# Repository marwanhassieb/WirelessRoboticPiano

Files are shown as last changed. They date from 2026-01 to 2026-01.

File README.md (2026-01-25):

# Wireless Robotic Piano (9-DOF Tele-operation System) 🎹🤖

**An automatic control systems project featuring a compact actuator system capable of playing 18 piano keys using only 9 motors.**

## 📂 Project Resources
* **[View Project Slides & Circuit Diagram (PDF)](./Wireless%20Robotic%20Piano.pdf)** *(Note: Click to view architecture)*
* **[View Source Code](./Piano_Code.ino)**
* ## ⚙️ Mechanical Design (SolidWorks)
**[📂 View CAD Files & 3D Models](./Mechanical_Design)**

We utilized **SolidWorks** to design a custom chassis that integrates the servo motors and electronics into a compact form factor.

* **Design Intent:** Minimized footprint to fit 9 motors within the span of 18 standard piano keys.
* **Mounting Strategy:** Designed custom brackets for the SG90 servos to ensure rigid mounting, preventing mechanical "play" (wobble) during high-speed actuation.
* **Simulation:** Validated the servo horn travel paths in CAD to ensure the 55° (CW) and 60° (CCW) angles would perfectly strike the key centers without collision.

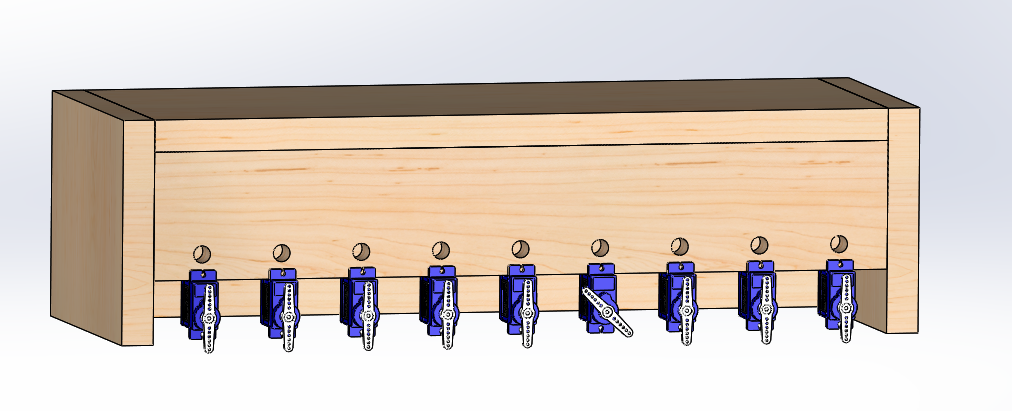
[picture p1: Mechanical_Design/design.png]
CAD Render


---

## 🔧 Technical Breakdown

### 1. Kinematics & Actuation
* **Optimization:** Solved hardware constraints by designing a **Bi-directional Actuation** mechanism. Each Servo controls two distinct outputs (CW → Key A, CCW → Key B), effectively doubling the system's mechanical resolution.
* **Hardware:** 9x SG90 Micro Servos with custom direct-drive horns.

### 2. Power Integrity & Safety
* **Problem:** Non-linear current demand (up to 4A peak) caused brownouts.
* **Solution:** Integrated an **XL4015 DC-DC Buck Converter** to step down 12V Li-Ion sources to a regulated 6V/5A rail. This isolated the high-current motor load from the microcontroller's logic.

### 3. Embedded Software & Architecture
* **Controller:** Arduino Uno.
* **Communication:** HC-05 Bluetooth Module (UART) using `SoftwareSerial`.
* **Latency:** Tuned signal timing (120ms actuation window) to ensure responsive playback.

---

## 🎮 Manual Control Map (ASCII Interface)

We implemented a real-time ASCII-to-Angle interface for wireless tele-operation.

| Letter | Note | Servo ID | Direction |
| :---: | :--- | :---: | :--- |
| **a** | Do | 0 | Left |
| **b** | Re | 1 | Left |
| **c** | Mi | 0 | Right |
| **d** | Fa | 1 | Right |
| **e** | Sol | 2 | Left |
| **f** | La | 3 | Left |
| **g** | Si | 2 | Right |
| **h** | High Do | 3 | Right |
| **i** | High Re | 4 | Left |
| **j** | High Mi | 5 | Left |
| **k** | High Fa | 4 | Right |
| **l** | High Sol | 5 | Right |
| **m** | High La | 6 | Left |
| **n** | High Si | 7 | Left |
| **o** | High Do+ | 6 | Right |
| **p** | High Re+ | 7 | Right |
| **q** | High Mi+ | 8 | Left |
| **r** | High Fa+ | 8 | Right |

### Automatic Presets
* **`1`** : Happy Birthday 🎂
* **`2`** : Merry Christmas 🎄
* **`3`** : Twinkle Twinkle 🌟
* **`4`** : Jingle Bells 🔔
* **`5`** : Ode to Joy (Dual Octave) 🎻
## 👥 Contributors
This project was a collaborative effort.
* **[Marwan Hassieb]** - [GitHub](https://github.com/marwanhassieb)
* **[Saif Refaat]** - [LinkedIn](https://www.linkedin.com/in/saif-refaat-8884112aa/)
* **[Waleed Yasser]** - [LinkedIn](https://www.linkedin.com/in/waleed-yasser-b95b77306/)
* **[Ahmed Refaat]** - [LinkedIn](https://www.linkedin.com/in/ahmed-refaat-a36927321/)

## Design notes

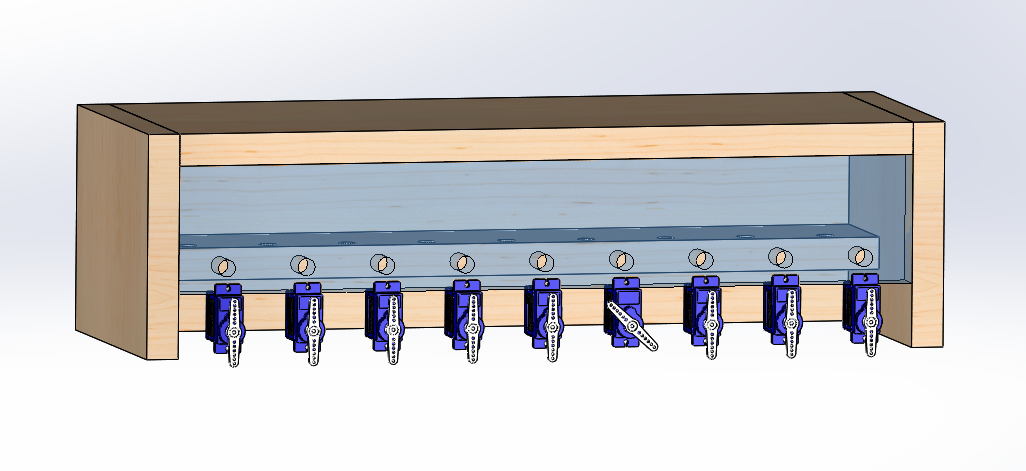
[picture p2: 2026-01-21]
Mechanical_Design/inside shot.png

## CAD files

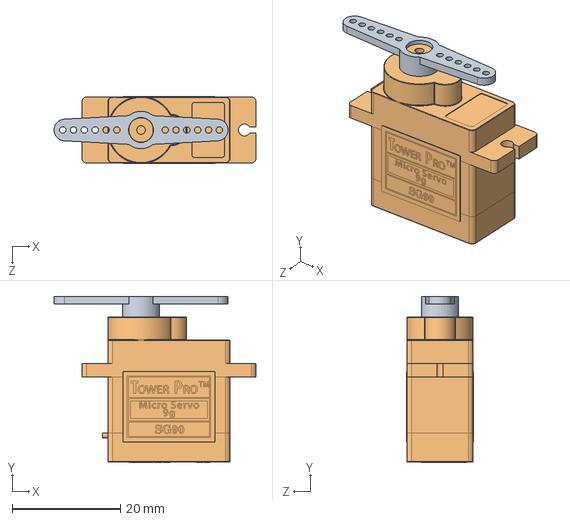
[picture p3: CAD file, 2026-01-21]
Mechanical_Design/servo.SLDASM
37.2 x 30.6 x 12.4 mm
SG90 - Micro Servo 9g - Tower Pro.1
SG90 - Micro Servo 9g - Tower Pro.3

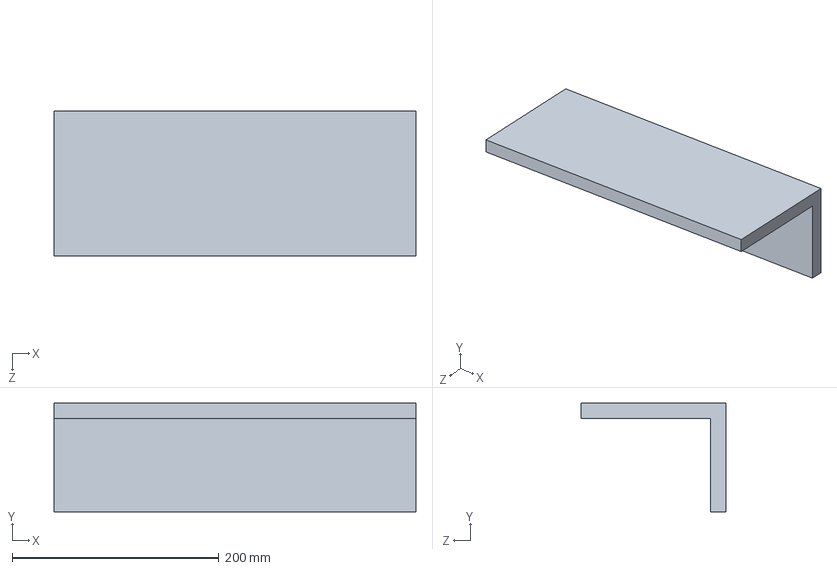
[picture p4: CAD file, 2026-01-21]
Mechanical_Design/top 2.SLDPRT
350.0 x 105.0 x 140.0 mm

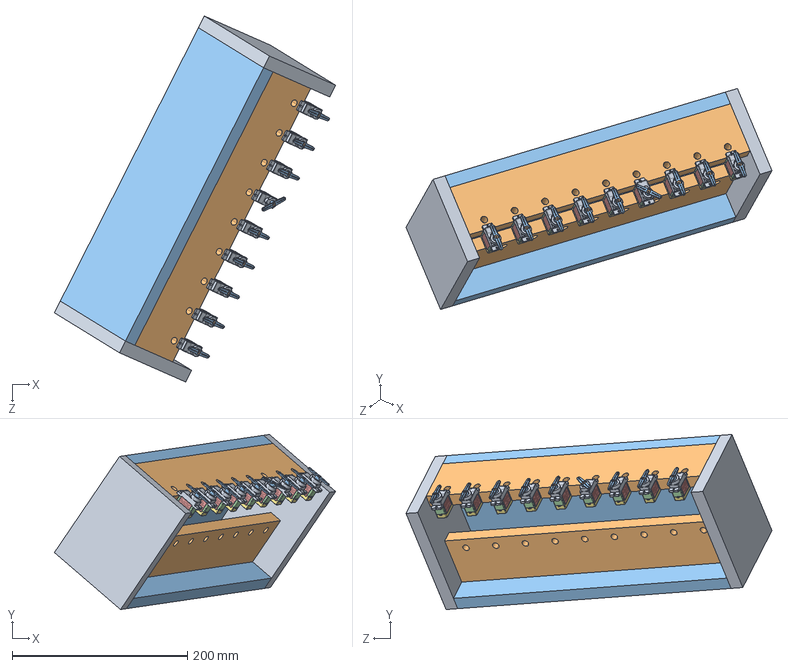
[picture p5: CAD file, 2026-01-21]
Mechanical_Design/chassis design.STEP
320.7 x 199.6 x 417.4 mm
sides x 2
top part x 2
top 2
SG90 - Micro Servo 9g - Tower Pro.1_Peça x 9
SG90 - Micro Servo 9g - Tower Pro.3_Peça x 9

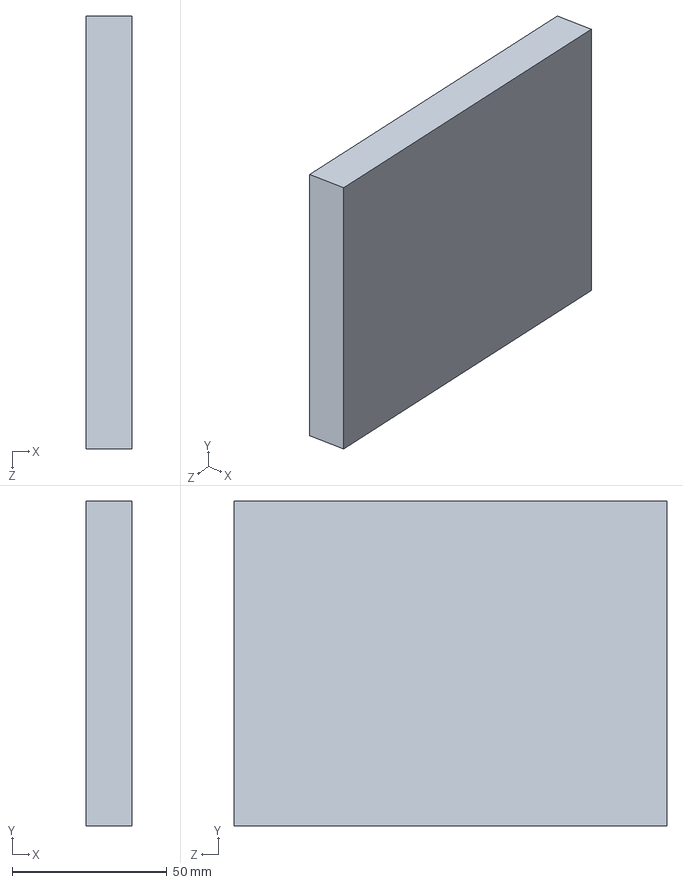
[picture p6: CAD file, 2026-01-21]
Mechanical_Design/sides.SLDPRT
15.0 x 105.0 x 140.0 mm

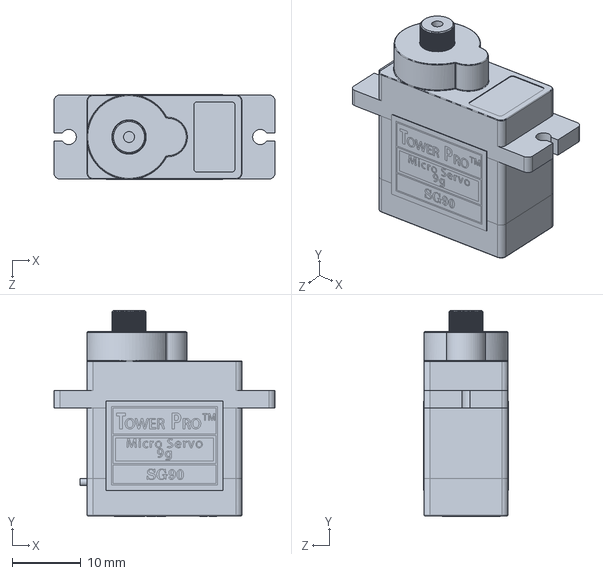
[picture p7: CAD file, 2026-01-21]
Mechanical_Design/SG90 - Micro Servo 9g - Tower Pro.1.SLDPRT
32.1 x 30.0 x 12.4 mm

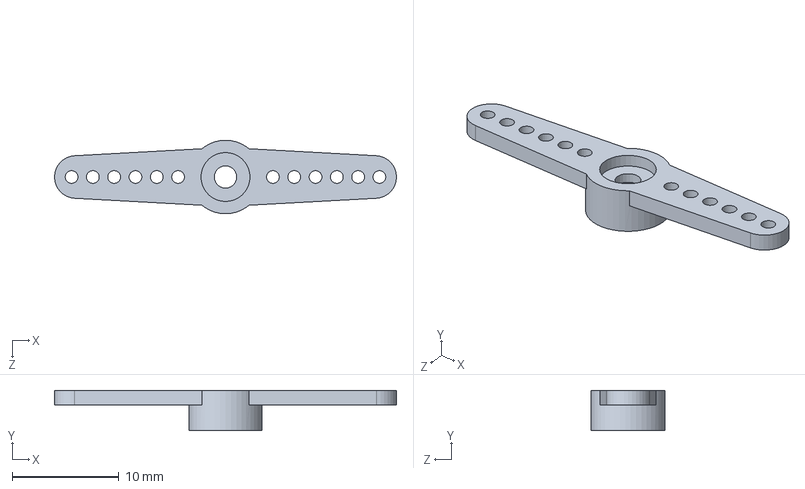
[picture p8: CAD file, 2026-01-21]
Mechanical_Design/SG90 - Micro Servo 9g - Tower Pro.3.SLDPRT
32.1 x 3.80 x 6.90 mm

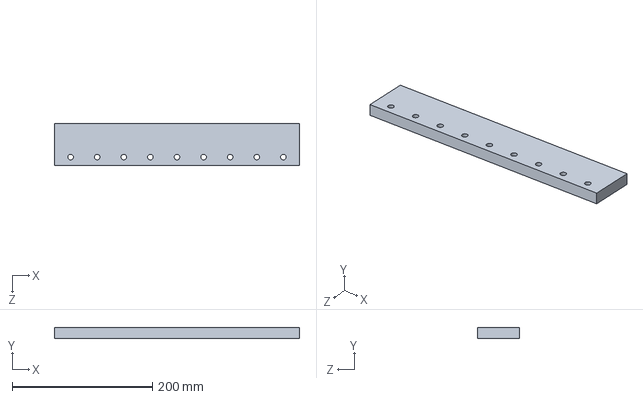
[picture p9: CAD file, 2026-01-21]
Mechanical_Design/top part.SLDPRT
350.0 x 15.0 x 60.0 mm

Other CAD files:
Mechanical_Design/chassis design.SLDASM

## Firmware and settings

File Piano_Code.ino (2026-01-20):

#include <Servo.h>
#include <SoftwareSerial.h>


SoftwareSerial BTSerial(10, 11); 

Servo myServos[9];

// The Arduino Pins: 2, 3, 4, 5, 6, 7, 8, 9, 12
int servoPins[] = {2, 3, 4, 5, 6, 7, 8, 9, 12};

// --- ANGLES ---
#define ANG_CENTER  90
#define ANG_LEFT    145
#define ANG_RIGHT   30
#define PRESS_TIME  120
int noteToServo[] = {0, 1, 0, 1, 2, 3, 2, 3, 4, 5, 4, 5, 6, 7, 6, 7, 8, 8};

int noteToDir[]   = {1, 1,-1,-1, 1, 1,-1,-1, 1, 1,-1,-1, 1, 1,-1,-1, 1,-1};

void setup() {
  Serial.begin(9600);
  BTSerial.begin(9600);
  Serial.println("9-Servo Piano Ready!");

  // Attach all 9 servos
  for(int i=0; i<9; i++) {
    myServos[i].attach(servoPins[i]);
    myServos[i].write(ANG_CENTER); 
    delay(50);
  }
}

void loop() {
  if (BTSerial.available()) {
    char cmd = BTSerial.read();
    Serial.write(cmd); 

    // Manual Play: (Letters 'a' through 'r')
    if(cmd >= 'a' && cmd <= 'r') {
      int note = cmd - 'a';
      playNote(note);
    }
    // Song Selection
    else if(cmd == '1') playHappyBirthday();
    else if(cmd == '2') playMerryChristmas();
    else if(cmd == '3') playTwinkleTwinkle(); 
    else if(cmd == '4') playJingleBells();    
    else if(cmd == '5') playOdeToJoy();    
  }
}

void playNote(int noteID) {
  // Safety Limit
  if(noteID > 17) return; 

  int servoID = noteToServo[noteID];
  int direction = noteToDir[noteID];
  
  if(direction == 1) {
    myServos[servoID].write(ANG_LEFT);
    delay(PRESS_TIME);
    myServos[servoID].write(ANG_CENTER);
  } else {
    myServos[servoID].write(ANG_RIGHT);
    delay(PRESS_TIME);
    myServos[servoID].write(ANG_CENTER);
  }
  delay(50); // Small pause between notes
}

// SONGS

void playHappyBirthday() {
  playNote(0); delay(150); playNote(0); delay(150);
  playNote(1); delay(300);
  playNote(0); delay(300);
  playNote(3); delay(300);
  playNote(2); delay(600);
  delay(300);
  playNote(0); delay(150); playNote(0); delay(150);
  playNote(1); delay(300);
  playNote(0); delay(300);
  playNote(4); delay(300);
  playNote(3); delay(600);
}

void playMerryChristmas() {
  playNote(0); delay(300);
  playNote(3); delay(300);
  playNote(3); delay(150); playNote(4); delay(150);
  playNote(3); delay(150); playNote(2); delay(150);
  playNote(1); delay(300); playNote(1); delay(300);
  playNote(1); delay(300); playNote(4); delay(300);
  playNote(4); delay(150); playNote(5); delay(150);
  playNote(4); delay(150); playNote(3); delay(150);
  playNote(2); delay(300); playNote(0); delay(300);
}

void playTwinkleTwinkle() {
  playNote(0); delay(300); playNote(0); delay(300);
  playNote(4); delay(300); playNote(4); delay(300);
  playNote(5); delay(300); playNote(5); delay(300);
  playNote(4); delay(600);
  
  delay(300);
  playNote(7); delay(300); playNote(7); delay(300); 
  playNote(11); delay(300); playNote(11); delay(300); 
  playNote(12); delay(300); playNote(12); delay(300); 
  playNote(11); delay(600); 
}

void playJingleBells() {
  playNote(2); delay(200); playNote(2); delay(200); playNote(2); delay(400);
  playNote(2); delay(200); playNote(2); delay(200); playNote(2); delay(400);
  playNote(9); delay(200); playNote(9); delay(200); playNote(9); delay(400); 
  playNote(9); delay(200); playNote(11); delay(200); 
  playNote(7); delay(200); playNote(8); delay(200);  
  playNote(9); delay(600); 
}

void playOdeToJoy() {
  playNote(2); delay(300); playNote(2); delay(300);
  playNote(3); delay(300); playNote(4); delay(300);
  playNote(4); delay(300); playNote(3); delay(300);
  playNote(2); delay(300); playNote(1); delay(300);
  playNote(0); delay(300); playNote(0); delay(300);
  playNote(1); delay(300); playNote(2); delay(300);
  playNote(2); delay(400); playNote(1); delay(150); playNote(1); delay(600);

  delay(500);

  playNote(9); delay(300); playNote(9); delay(300); 
  playNote(10); delay(300); playNote(11); delay(300); 
  playNote(11); delay(300); playNote(10); delay(300);
  playNote(9); delay(300); playNote(8); delay(300);  
  playNote(7); delay(300); playNote(7); delay(300); 
  playNote(8); delay(300); playNote(9); delay(300);
  playNote(9); delay(400); playNote(8); delay(150); playNote(8); delay(600);

  delay(300);
  playNote(16); delay(200); playNote(17); delay(200); playNote(16); delay(600);
}
